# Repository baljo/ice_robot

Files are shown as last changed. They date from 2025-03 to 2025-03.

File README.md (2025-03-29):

# Ice Curing Rover

## The Problem

Too many persons get injured (or worse) due to icy conditions, in the US alone there are [tens of thousands of injuries](https://www.bls.gov/opub/ted/2016/42480-work-injuries-involved-ice-sleet-or-snow-in-2014.htm) involving ice, sleet, or snow. Typically, the city or state is responsible for ensuring public roads are safe, but responsibility shifts to you at the start of your own driveway. Thus, you need to ensure it is safe yourself. You can, of course, salt or sand your icy driveway manually, just as you can mow your lawn, vacuum your home, or wash dishes by hand. While curing your driveway from ice might be enjoyable for some, it’s tedious for others. If you find yourself in the latter group, read on for a solution!

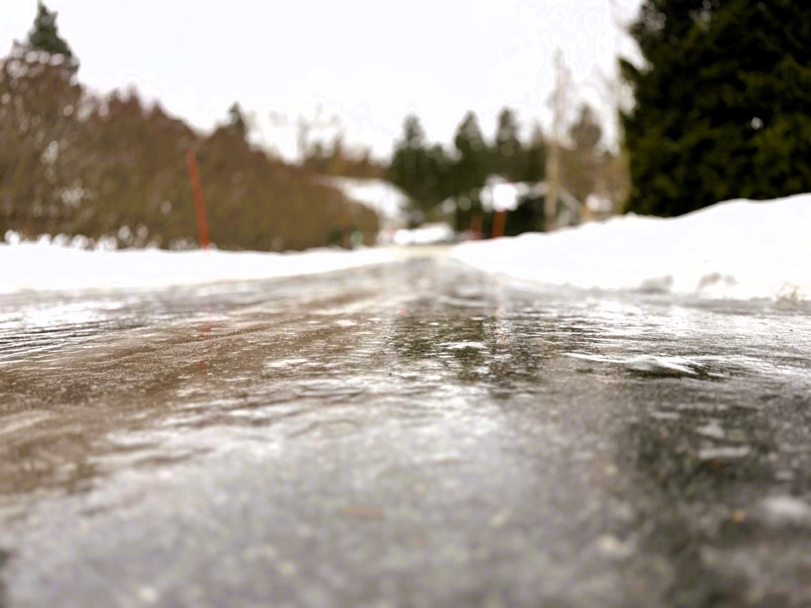
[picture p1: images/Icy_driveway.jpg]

--*Finland, February 22, 2025*--

## The Solution

Meet **Ice Beat-Le**, a symphatethic looking rover designed to combat ice by spreading salt, sand, or other suitable materials on your driveway or path. The rover is driven by six wheels and navigates using IR sensors ("eyes") to lock onto an IR beacon.

For the rover’s MCU, I selected the Particle Photon 2 because it's versatile, powerful, yet easy to work with. The IR beacon currently uses a Propeller Activity Board from Parallax because it includes an onboard D/A chip. If another Photon 2 had been available, I would likely have redesigned the beacon circuit and software to use Pulse Width Modulation (PWM) instead of the D/A chip.

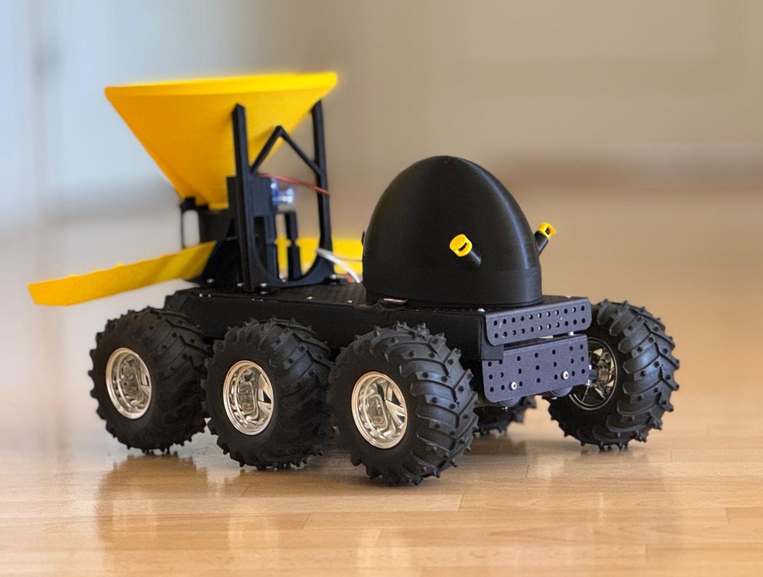
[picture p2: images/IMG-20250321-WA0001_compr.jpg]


### How does it work?

Although the rover looks complex due to its electronic components, motors, servo, and mechanical parts, it is actually quite straightforward, even minimalistic. There are no unnecessary bells and whistles - the rover does exactly what it’s intended to do, nothing more, nothing less. However, the journey of designing and building the rover involved overcoming numerous technical challenges.

#### Navigation

Navigation is achieved using an IR beacon transmitting a 38 kHz IR signal of varying intensity, utilizing the Sony protocol—the same used by many TV remote controls. Unfortunately, the IR receivers ("eyes") on the rover can only detect whether a modulated IR signal is present, not its intensity. This limitation makes it impossible to navigate using a constant IR signal alone, as the rover wouldn’t be able to determine if it's to the left or right of the beacon’s beam.

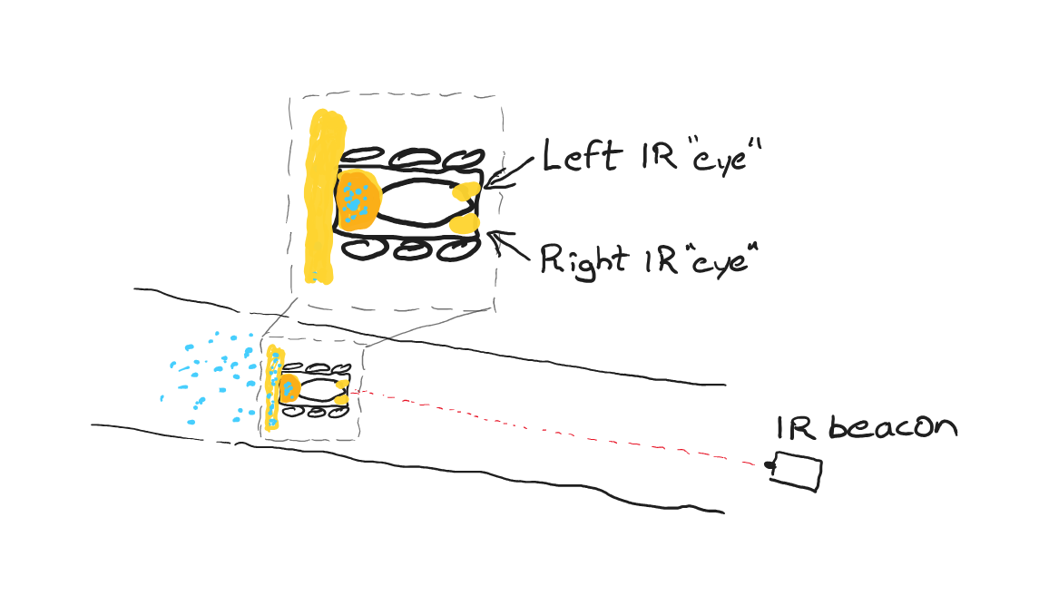
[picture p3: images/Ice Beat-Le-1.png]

--*Rover on a driveway*--

To overcome this issue, I adopted a [solution](https://learn.parallax.com/courses/ir-beacon-seeking-activitybot-with-blocklyprop/) that involves varying the intensity of the IR signal. By modulating both the brightness and pulsing of the beacon, the rover measures how frequently it detects the IR signal, allowing it to determine its orientation relative to the beacon.

To generate both the modulated (pulsed) IR signal AND the varying brightness, two different signals are fed into the LED at the same time. The positive leg of the LED connects to an I/O pin, where the code is sending it pulses by turning it on and off 38000 times per second. The negative leg of the LED connects to a D/A-pin, which is changing its voltage output from 0V (full brightness for the LED) to 1.6V (nearly off). Why is 0V bright and 1.6V dim? Because this is where the negative leg is connected. The result is that the “Sawtooth”-like output of D/A is subtracted from the 3.3V pulses from the I/O pin:

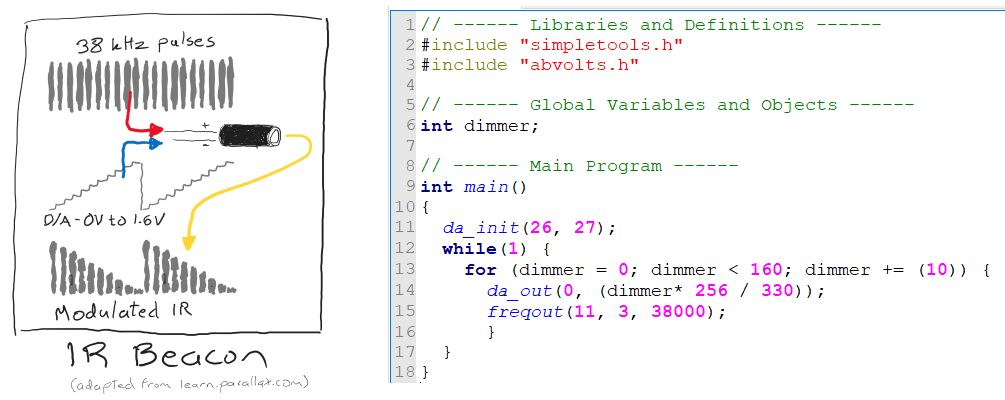
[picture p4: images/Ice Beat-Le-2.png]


The rover counts how often each IR sensor detects the beacon's light. If one side detects fewer pulses than the other (indicating that side is farther from the beacon), the rover turns in the opposite direction. E.g., in the driveway sketch further above, the left sensor receives less light than the right, and thus the rover turns right. Since IR signals can be slightly erratic due to external interference, each receiver uses a moving average to stabilize readings.

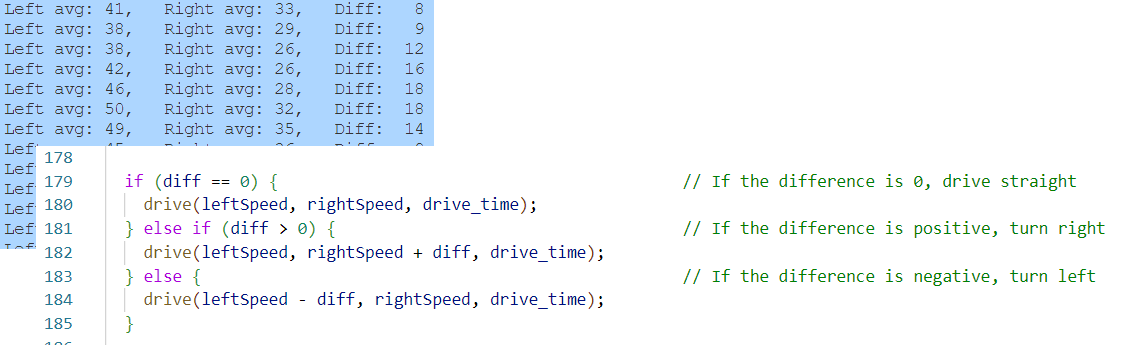
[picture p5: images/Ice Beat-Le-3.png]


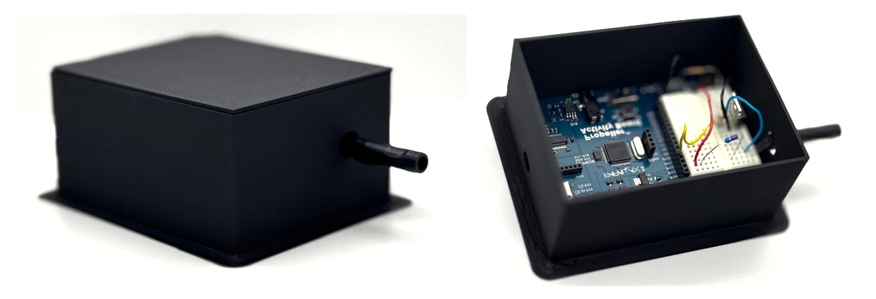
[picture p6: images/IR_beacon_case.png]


#### Sanding/Salting 

In the name of simplicity, and instead of inventing a salting mechanism needing a strong motor, I decided to use a force available to all of us for free → gravity. Sand, salt, or any other suitable material is poured into the container which has a hole in the bottom. To avoid that the sand falls away directly, a servo-controlled lid is opened or closed within the main control program. The sand falls down on the spreader which spreads it over approximately half a meter in width as the rover moves forward. If large particles are used, there's a risk of them clogging the container opening. However, as the rover doesn't have differential steering, it twitches a bit when alternating between driving, turning, and coasting, and I found out that this leads to that potential clogs are easily dissolved.

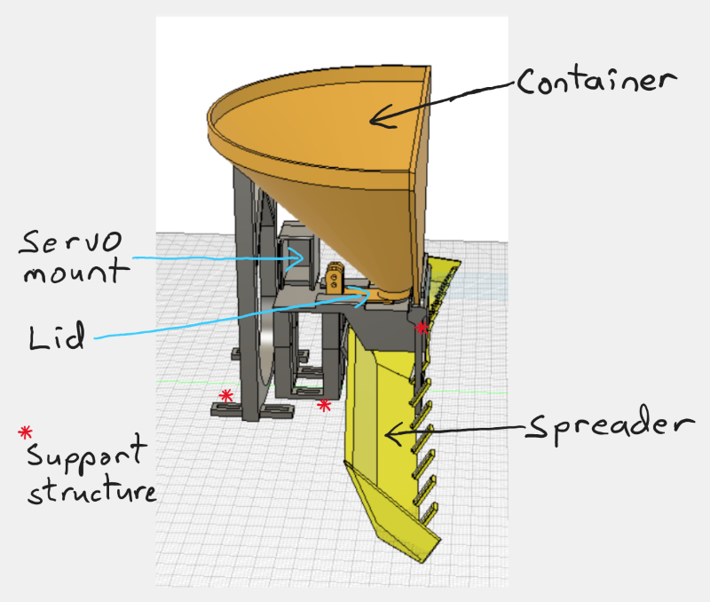
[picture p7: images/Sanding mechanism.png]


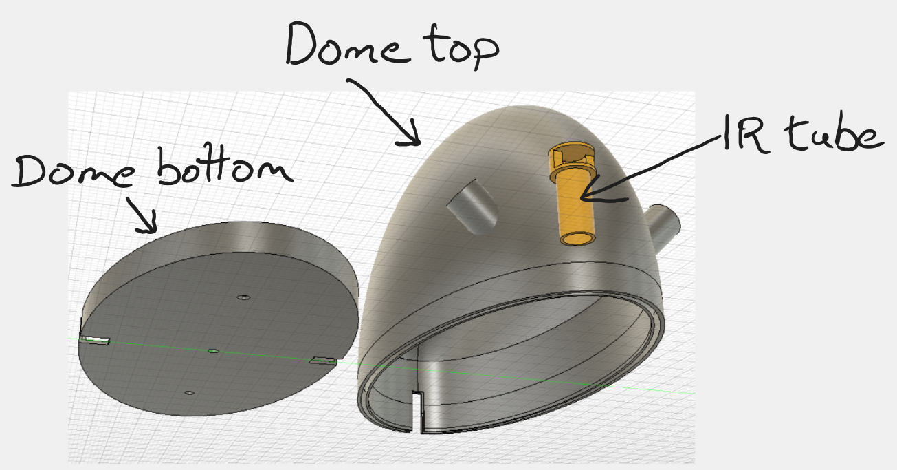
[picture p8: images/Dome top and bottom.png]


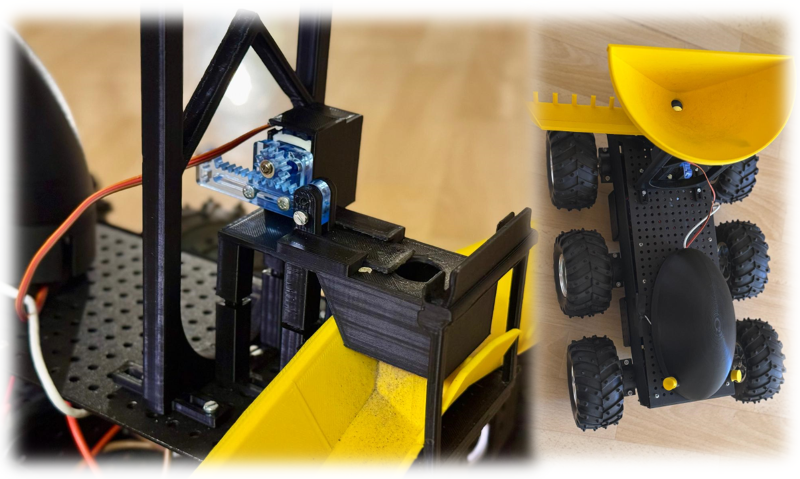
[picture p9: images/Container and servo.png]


## Materials Required

**Rover**
- [Particle Photon 2](https://store.particle.io/products/photon-2?srsltid=AfmBOopQNaLMpaWTah99rLqtw8SrwQJ14wpPAscubC-w2jhXiWBzn8VZ)
- Dagu Wild Thumper 6WD (my rover included 6 motors and 2 HB-25 motor controllers)
- 38 kHz Infrared IR Receiver, e.g. [this](https://www.jameco.com/z/TSOP34138-Vishay-Infrared-IR-Receiver-38Khz-Carrier-Frequency-Use-with-Parallax-350-00017-Boe-Sumo_2109691.html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) 
- [Kitronik Linear Actuator Kit](https://kitronik.co.uk/products/2595-linear-actuator?_pos=3&_sid=e648f346a&_ss=r)
- 5V power for the Photon 2, e.g. a small powerbank
- separate power supply recommended for the motors, max 7.5 VDC; remember to connect grounds
- large breadboard
- 2 servo headers (for HB-25 motor controllers)
- Two 10kΩ resistors
- assorted wires

**IR Beacon**
- [Propeller Activity Board](https://www.parallax.com/product/propeller-activity-board-wx/), or any other microcontroller board with an D/A-chip. It is also possible to use PWM (Pulse Width Modulation) to replicate change in intensity.
- [TSAL6200 IR LED](https://www.partco.fi/en/leds/special-purpose-leds/17474-tsal6200.html), TSAL6100 even better as it has narrower angle
- [IRLZ44N Mosfet](https://www.partco.fi/en/electronic-components/actives/bjt-and-fet/switching-fets-n-channel/5057-irlz44n.html)
- 2.2Ω Resistor
- 10kΩ Resistor
- 5V power for the microcontroller, e.g. a powerbank
- assorted wires

**Note:** Ensure the program cycles the IR LED; constant operation may burn out the LED or resistor. A MOSFET is required to handle higher current beyond the MCU’s capability.

## Assembly Instructions

- Assemble the rover itself according to instructions, my rover came preassembled as it was a used one.

- 3D-print the different components, most of them do not need supports if they are rotated properly. For most parts I used an infill of 10-20 %. 
- Feel free to redesign the components according to your platform and needs. Remember to add tolerances when designing pieces that need to fit together!

### Wiring and Schematics

#### Rover Electronics

- Photon 2 connections

| Photon 2 | To | 
|--- |---|
| D15 | Left motor signal  |  
| D1 | Right motor signal |  
| D2 | Left IR signal |  
| D10 | Right IR signal | 
| D16 | Lid servo signal |  
| VUSB | Lid servo power | 

- Fritzing diagram 

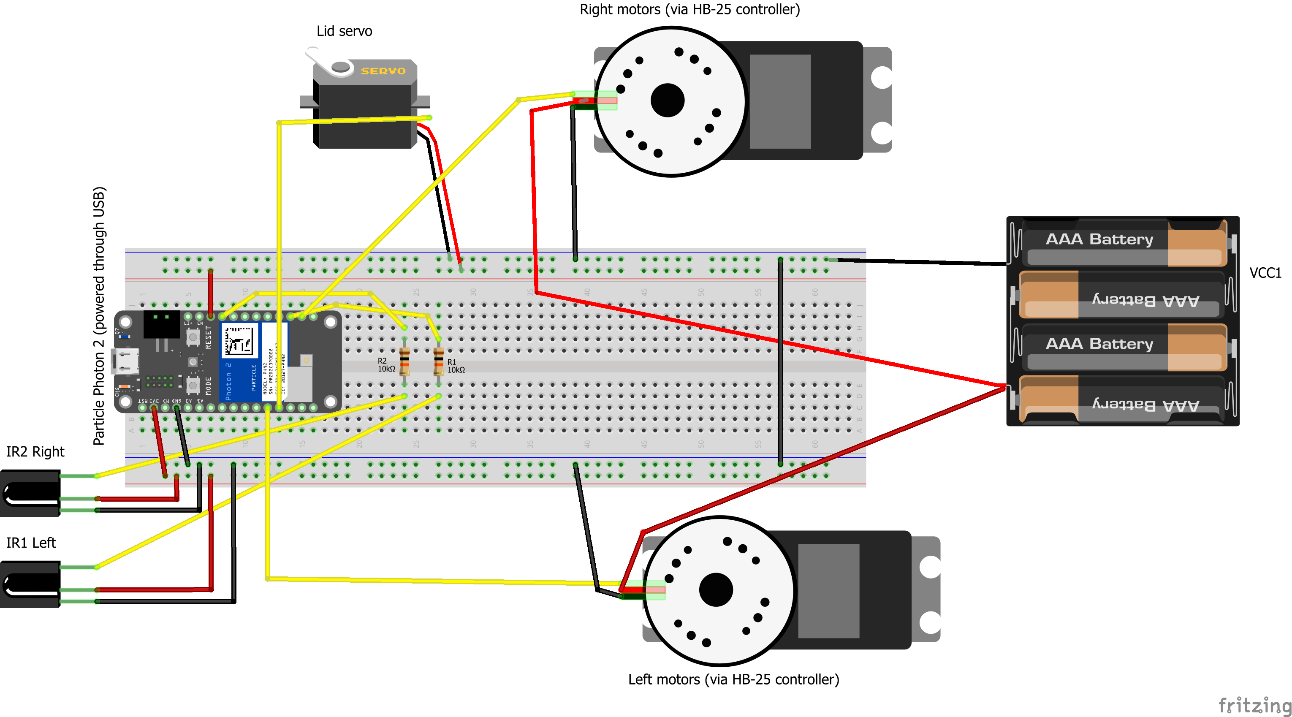
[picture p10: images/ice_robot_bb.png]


- Close-up photo, do note that the lid controlling servo is left out of the photo for clarity, it is connected to VUSB and D16.

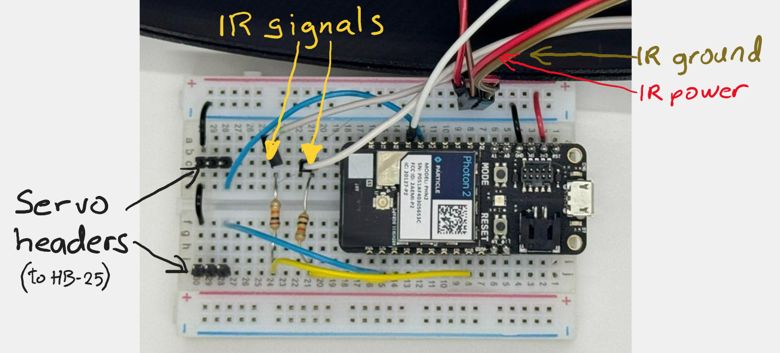
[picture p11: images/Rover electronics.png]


#### IR Beacon

- Fritzing diagram. In my setup I'm using the Propeller Activity Board as it has a D/A-chip.

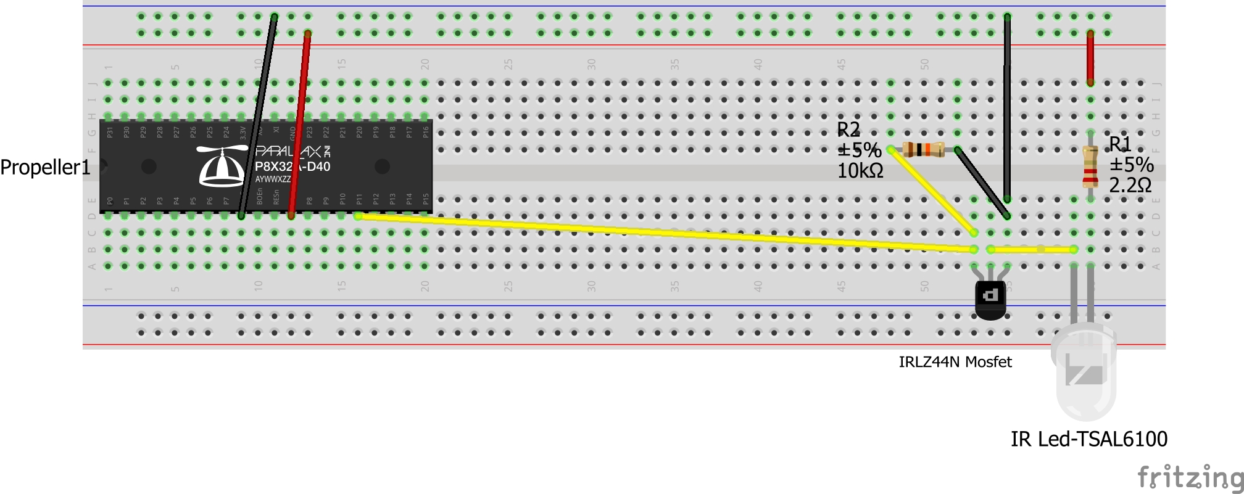
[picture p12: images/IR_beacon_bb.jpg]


- Close-up photo. To narrow the infrared beam a bit, the IR LED is equipped with a plastic straw enclosed in black electronic tape.

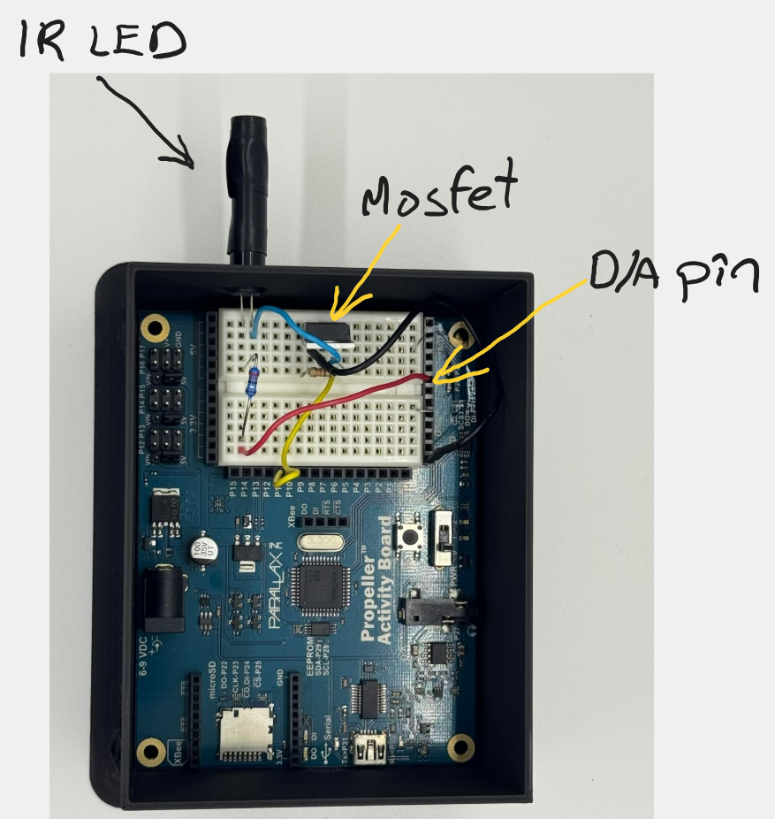
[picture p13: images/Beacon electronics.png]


## Software Description

Below a description of the main functions.

### IR Beacon

The beacon program is very simple, it pulses out IR light with a frequency of 38 kHz, in this case using pin 11 on the Propeller MCU. Every pulse is 3 milliseconds in length. The intensity is changed between nearly off until fully lit (330 = 3.3V).

```
// ------ Libraries and Definitions ------
#include "simpletools.h"
#include "abvolts.h"

// ------ Global Variables and Objects ------
int dimmer;

// ------ Main Program ------
int main() {
  da_init(26, 27);
  while(1) {
    for (dimmer = 0; dimmer < 160; dimmer += (10)) {
      da_out(0, (dimmer* 256 / 330));
      freqout(11, 3, 38000);
    }
  }
}

```

### Photon 2

- The function `IR_read` reads the IR sensors 96 times per loop and accumulates the pulses read per sensor. The higher the number is, the closer or more aligned the sensor is to the beacon.

```
// Read the IR sensors
// leftOut and rightOut are passed by reference
// They will be updated with the number of times the IR sensor was triggered
// The higher the number, the closer the sensor is to an object

void IR_read(int &leftOut, int &rightOut) {
  int leftIR = 0;
  int rightIR = 0;
  
  // Sample 96 times (16 * 6)
  for(int n = 0; n < 96; n++) {
    leftIR  += !digitalRead(LEFT_IR_PIN);                   // Read the digital value of the IR sensor
    rightIR += !digitalRead(RIGHT_IR_PIN);                  // Read the digital value of the IR sensor
    delay(1);                                               // 1 ms between samples
  }
  
  // Assign results to the provided references
  leftOut  = leftIR;
  rightOut = rightIR;
}
```

- The function `drive` drives the rover by the speed received for each side. The motors are off when the value is 90, and as they need to rotate in opposite directions the given speed is added to 90 for the left motors, and subtracted from 90 for the right motors. 

```
void drive(int left_speed, int right_speed, int time) {
  left.write(90 + left_speed);    // Move left motor forward
  right.write(90 - right_speed);  // Move right motor forward
  delay(time);                    // Delay selected time
}
```

- The main loop consists of reading the IR sensors, calculate a rolling average for each of them, and based on possible difference between the readings turn right or left. As the rover's minimum speed is too fast indoors, it is alternating between driving forware, coasting, or turning.

```
  IR_read(leftIR, rightIR);                                 // Read the IR sensors  
----------------------
  int left_avg = calculateRollingAverage(leftIR, 0);        // Rolling average for Sensor 1
  int right_avg = calculateRollingAverage(rightIR, 1);      // Rolling average for Sensor 2
  int diff = coeff * (left_avg - right_avg);                // Calculate the difference between the IR sensors
----------------------
  int left_avg = calculateRollingAverage(leftIR, 0);        // Rolling average for Sensor 1
  int right_avg = calculateRollingAverage(rightIR, 1);      // Rolling average for Sensor 2
  int diff = coeff * (left_avg - right_avg);                // Calculate the difference between the IR sensors
----------------------
// If either leftIR or rightIR is very low, don't move
  while (left_avg <= 2 || right_avg <= 2 && left_avg != right_avg) {
    Log.info("Seeking IR signal");

    IR_read(leftIR, rightIR);
    left_avg = calculateRollingAverage(leftIR, 0);          // Rolling average for Sensor 1
    right_avg = calculateRollingAverage(rightIR, 1);        // Rolling average for Sensor 2
    diff = coeff * (left_avg - right_avg);                  // Calculate the difference between the IR sensors

    Log.info("   Left avg: %2d,   Right avg: %2d,   Diff: %3d", left_avg, right_avg, left_avg - right_avg);
  }

  if (diff == 0) {                                          // If the difference is 0, drive straight
    drive(leftSpeed, rightSpeed, drive_time);
  } else if (diff > 0) {                                    // If the difference is positive, turn right
    drive(leftSpeed, rightSpeed + diff, drive_time);
  } else {                                                  // If the difference is negative, turn left
    drive(leftSpeed - diff, rightSpeed, drive_time);
  }

  drive(leftSpeed / 3, rightSpeed / 3, drive_time);         // Drive forward at a slower speed, otherwise the robot will drive too fast
```

## Final Demonstration

A YouTube video is found [here](https://youtu.be/t5bE52Lg39M).



## Conclusion & Next Steps

### Issues overcome

As mentioned earlier, while the final result appears minimalistic, the journey to achieve it was neither simple nor straightforward. Indeed, there were several challenges and setbacks along the way. Finding a reliable solution for outdoor navigation took considerable experimentation - I had to acquire and test various IR LEDs and receivers extensively before finding an effective combination. Additionally, learning Fusion 360 from scratch, designing twelve distinct 3D-printed components, and printing numerous iterations consumed significant time and roughly one kilogram of filament, of which approximately 80% ended up as scrap.

### Future enhancements

This initial version of the rover isn't yet fully autonomous; for safety, it currently only moves when the IR beacon is transmitting. Presently, it moves forward and turns left or right as needed, but it would be relatively straightforward to add functionality enabling it to reverse its route or cover wider areas. Expanding the coverage could be achieved either by implementing a larger spreader mechanism or programming the rover to follow multiple parallel lanes.

To achieve full autonomy, adding bumper switches or distance sensors would allow obstacle avoidance, while integrating an odometer or a high-precision (centimeter-level) differential GPS would significantly enhance navigation capabilities—though these would add to the cost.

For permanent installations, the existing breadboard setup should be replaced by a custom PCB or at least a soldered protoboard. Additionally, the two separate battery systems currently in use could be consolidated into a single, higher-capacity battery for improved efficiency and runtime.

### Final Conclusions

This Ice Curing Rover, affectionately called Ice Beat-Le, is a six-wheeled autonomous vehicle that spreads sand or salt on icy driveways, helping reduce winter slip hazards. At the heart of the rover is the Particle Photon 2, whose powerful yet beginner-friendly platform made it easy to prototype, program, and control the robot’s complex behaviors with minimal overhead. Navigating via a modulated IR-beacon and using a gravity-fed dispenser controlled by a servo, the rover is a compact and cost-effective solution built with 3D-printed parts and off-the-shelf components. The Photon 2’s combination of real-time control, built-in connectivity, and versatility made it the ideal choice for this project - especially for balancing simplicity with performance. With a few additions, such as obstacle sensors or lane logic, the rover could easily evolve into a fully autonomous ice-clearing assistant.

While the *road* was bumpy to some *degree*, it *led* eventually to the goal, and it is now *ice* free! 

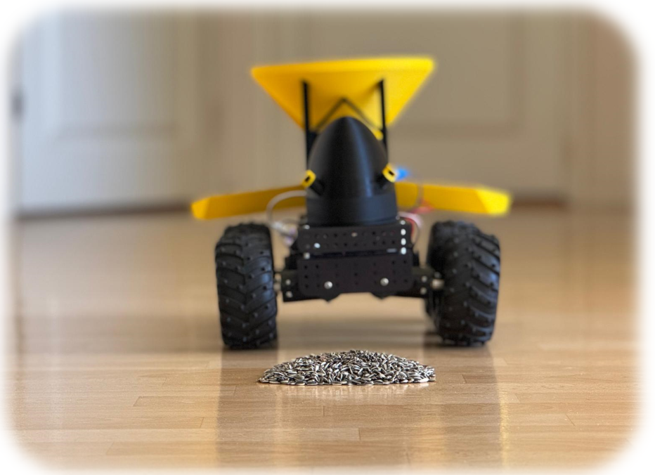
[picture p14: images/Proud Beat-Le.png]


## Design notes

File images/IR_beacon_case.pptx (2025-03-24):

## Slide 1

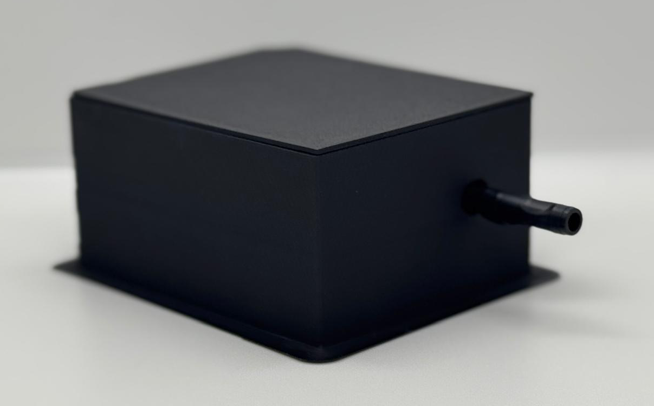
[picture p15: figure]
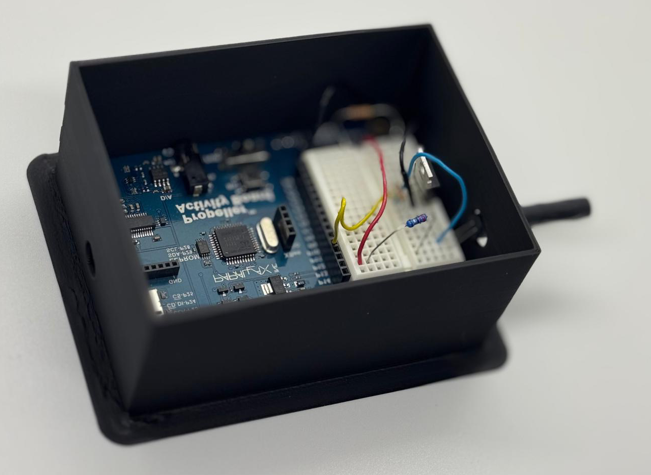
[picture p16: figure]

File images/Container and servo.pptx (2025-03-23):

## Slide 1

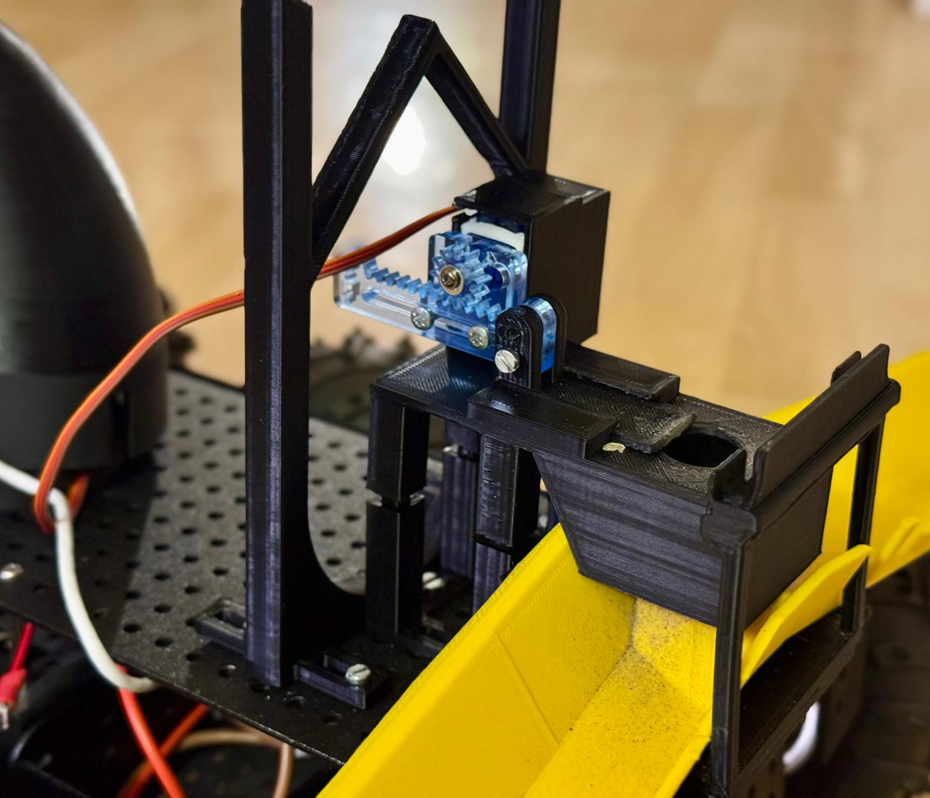
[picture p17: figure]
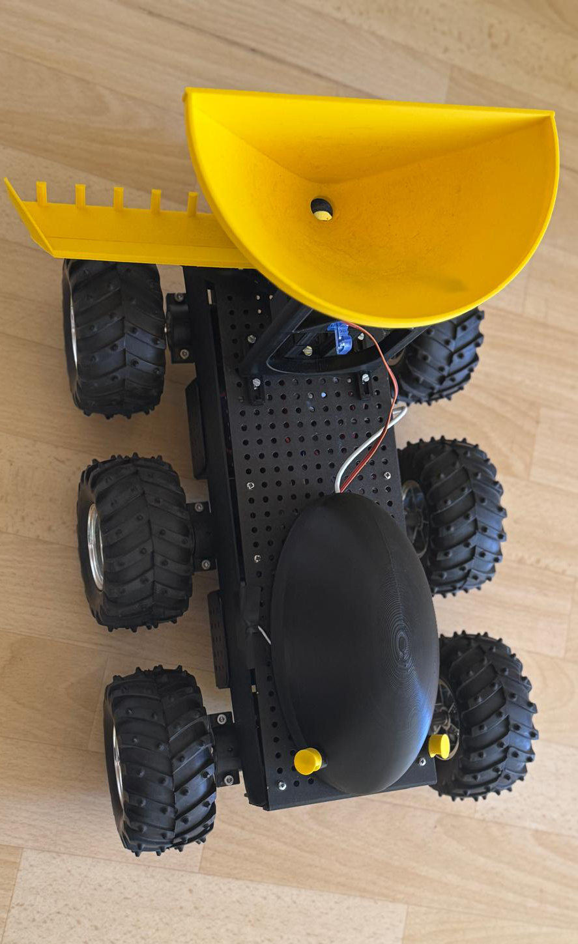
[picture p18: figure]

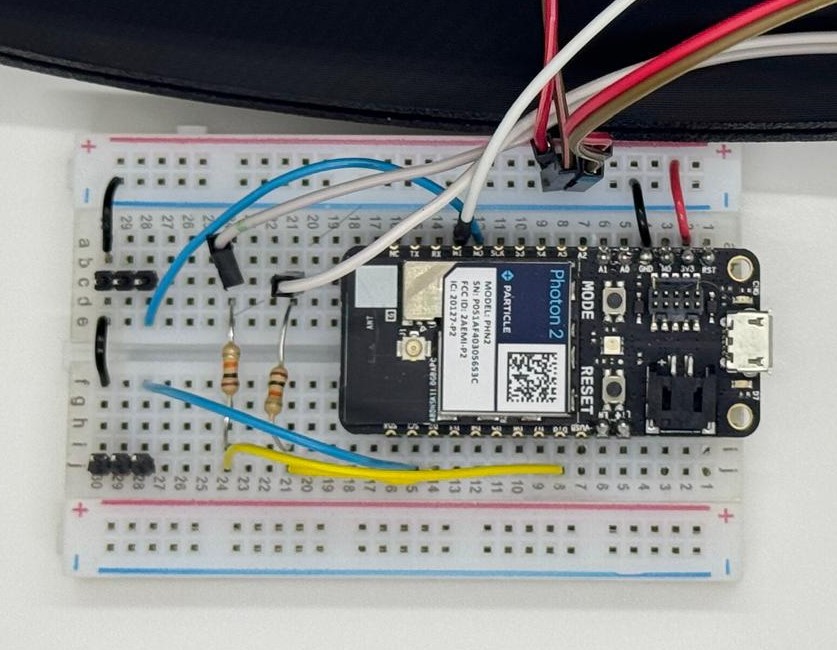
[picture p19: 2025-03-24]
images/Rover_electronics.jpg

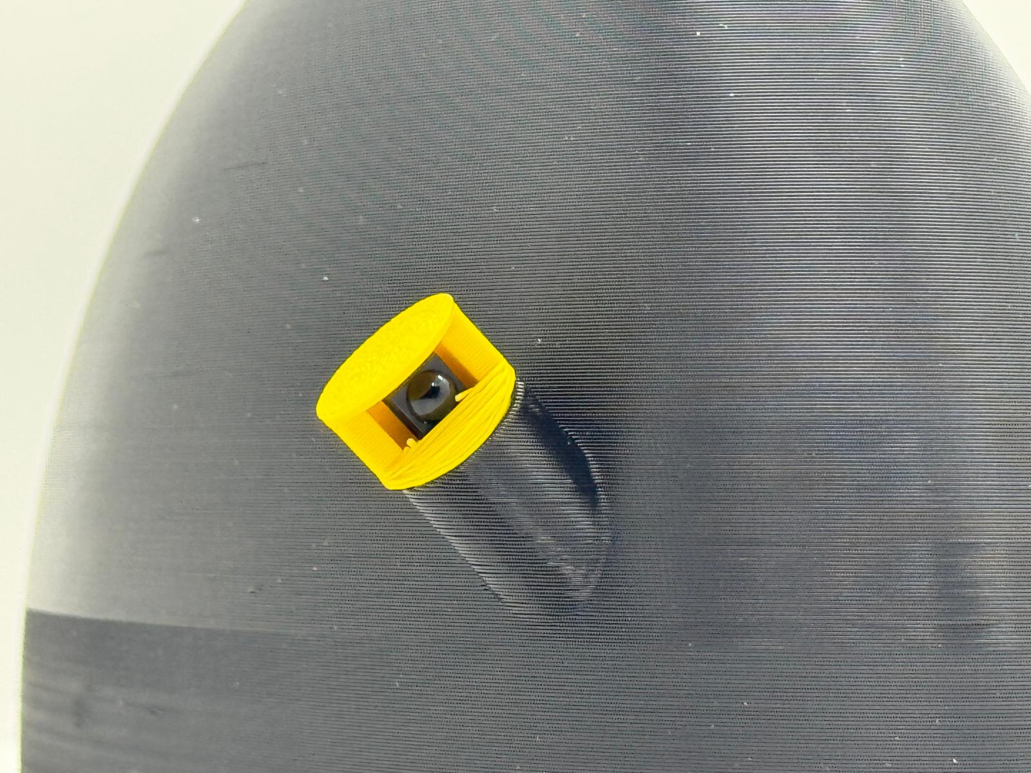
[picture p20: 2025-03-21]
images/IMG-20250321-WA0013.jpg

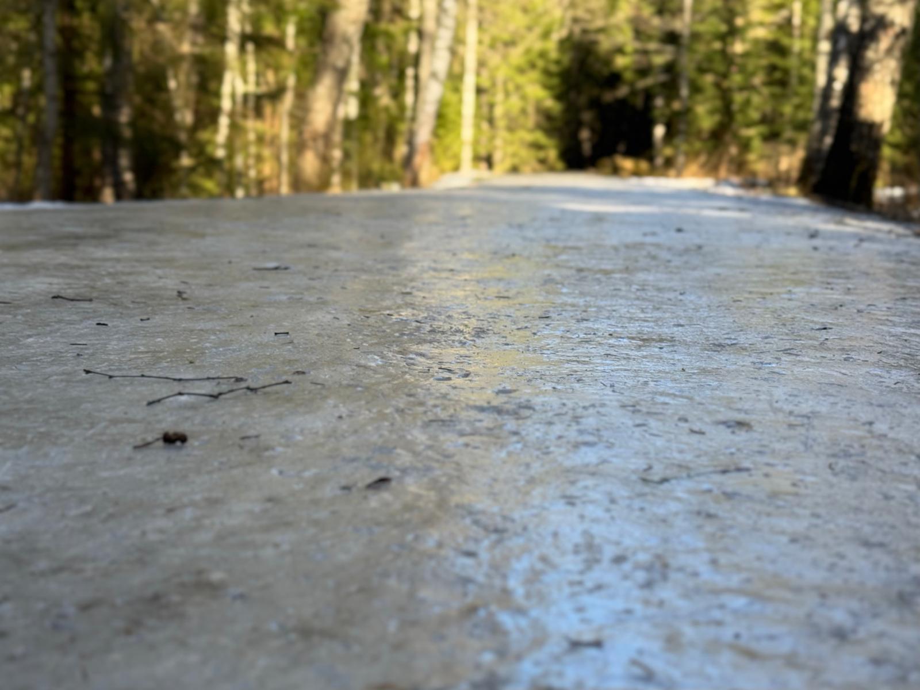
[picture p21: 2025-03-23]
images/Icy_driveway_2.jpg

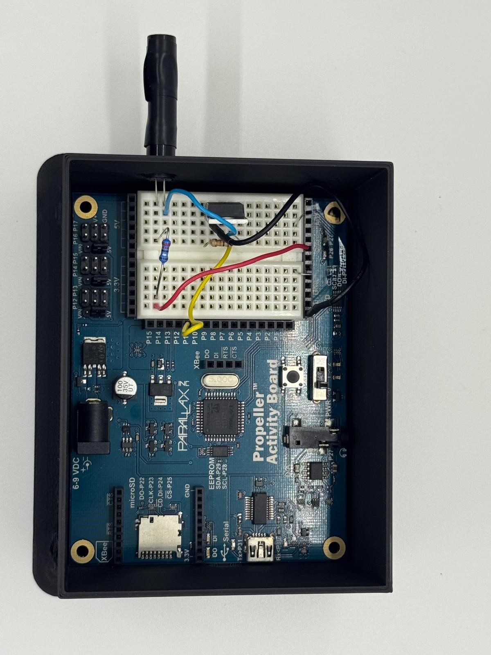
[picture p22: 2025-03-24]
images/IMG-20250321-WA0008.jpg

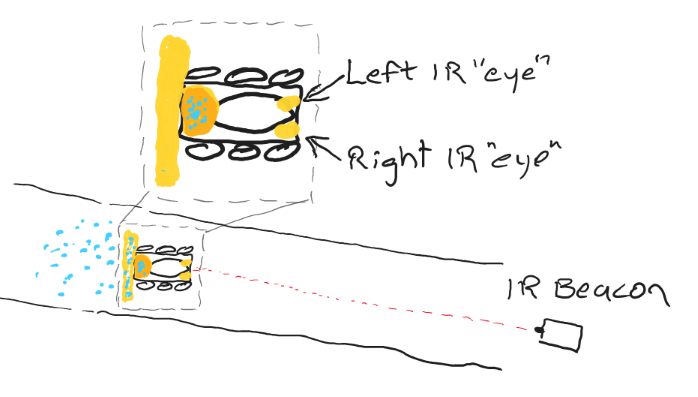
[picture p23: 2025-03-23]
images/Ice Beat-Le-01.png

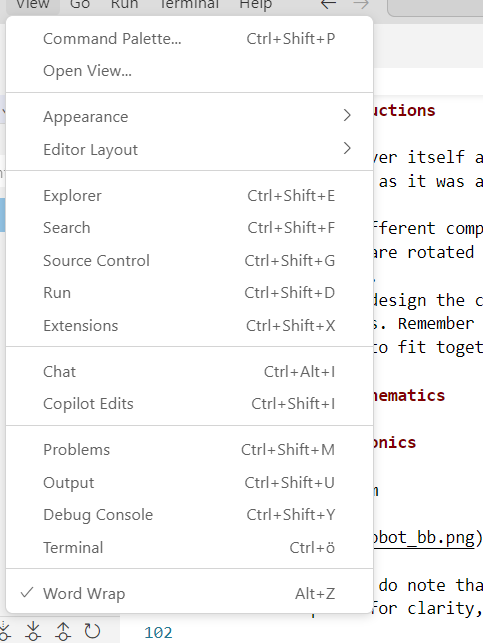
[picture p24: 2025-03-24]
image.png

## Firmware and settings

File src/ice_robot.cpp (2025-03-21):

/* 
 * Project Ice Beat-Le
 * Author: Thomas Vikström
 * Date: 21.3.2025
 * Description: This program is designed to control a robot with two motors and two IR sensors.
 * 
 */

// Include Particle Device OS APIs
#include "Particle.h"
#include <cstdlib> // Include the necessary library for random function


// Let Device OS manage the connection to the Particle Cloud
SYSTEM_MODE(AUTOMATIC);

// Run the application and system concurrently in separate threads
SYSTEM_THREAD(ENABLED);

// Show system, cloud connectivity, and application logs over USB
// View logs with CLI using 'particle serial monitor --follow'
SerialLogHandler logHandler(LOG_LEVEL_INFO);

Servo left;                                       // create servo object to control a servo
Servo right;                                      // create servo object to control a servo
Servo lid;                                        // create servo object to control a servo

const int LEFT_MOTOR_PIN = D15; 
const int RIGHT_MOTOR_PIN = D1;
const int LEFT_IR_PIN = D2;
const int RIGHT_IR_PIN = D10;
const int LID_PIN = D16;


// ------ Functions ------

void forward(int speed, int time) {
  left.write(90 + speed);   // Move left motor forward
  right.write(90 - speed);  // Move right motor forward
  delay(time);              // Delay selected time
}

void drive(int left_speed, int right_speed, int time) {
  left.write(90 + left_speed);    // Move left motor forward
  right.write(90 - right_speed);  // Move right motor forward
  delay(time);                    // Delay selected time
}

void stop(int time) {
  left.write(90);         // Stop both motors
  right.write(90);   
  delay(time);            // Delay selected time 
}


// Function to calculate the rolling average for a given sensor
float calculateRollingAverage(float newSample, int sensorID) {
  static int amount = 3;
  static float samples[2][3] = {{0}}; // Arrays to store the last 10 samples for two sensors
  static int index[2] = {0};          // Current index for each sensor
  static int count[2] = {0};          // Number of samples added (up to 10) for each sensor
  static float sum[2] = {0};          // Sum of the samples for each sensor

  // Subtract the oldest sample from the sum (if array is full)
  sum[sensorID] -= samples[sensorID][index[sensorID]];

  // Add the new sample to the array and update the sum
  samples[sensorID][index[sensorID]] = newSample;
  sum[sensorID] += newSample;

  // Update the index for the sensor
  index[sensorID] = (index[sensorID] + 1) % amount;

  // Increment count up to 10 for the sensor
  if (count[sensorID] < amount) {
      count[sensorID]++;
  }

  // Return the rolling average for the sensor
  return sum[sensorID] / count[sensorID];
}


// Read the IR sensors
// leftOut and rightOut are passed by reference
// They will be updated with the number of times the IR sensor was triggered
// The higher the number, the closer the sensor is to an object

void IR_read(int &leftOut, int &rightOut) {
  int leftIR = 0;
  int rightIR = 0;
  
  // Sample 96 times (16 * 6)
  for(int n = 0; n < 96; n++) {
    leftIR  += !digitalRead(LEFT_IR_PIN);                   // Read the digital value of the IR sensor
    rightIR += !digitalRead(RIGHT_IR_PIN);                  // Read the digital value of the IR sensor
    delay(1);                                               // 1 ms between samples
  }
  
  // Assign results to the provided references
  leftOut  = leftIR;
  rightOut = rightIR;
}


// --------------------------------------------------------------------------
// Open and close the lid
// --------------------------------------------------------------------------
void move_lid() {      

  int speed = 5;
  int wait = 15;
  int servo_pos = 0;              // variable to store the servo position


  for (servo_pos = 170; servo_pos >= 1; servo_pos -= speed) {
      lid.write(servo_pos);
      delay(wait);
  }

  delay(wait);

  for (servo_pos = 0; servo_pos < 170; servo_pos += speed) {   
    lid.write(servo_pos);
    delay(wait);
  }

}



void setup() {


  // Set up the IR sensors
  pinMode(LEFT_IR_PIN, INPUT);                               // sets the digital pin as input
  pinMode(RIGHT_IR_PIN, INPUT);                              // sets the digital pin as input

  // Set up the motors
  left.attach(LEFT_MOTOR_PIN);                               // attaches the left servo  to the servo object
  right.attach(RIGHT_MOTOR_PIN);                             // attaches the right servo to the servo object
  lid.attach(LID_PIN);                                       // attaches the lid servo to the servo object
}


void loop() {
  int leftIR = 0;
  int rightIR = 0;
  
  IR_read(leftIR, rightIR);                                 // Read the IR sensors  

  int leftSpeed = 23;                                       // Set the speed for the left motor (the left motor is slower)
  int rightSpeed = 20;                                      // Set the speed for the right motor
  int drive_time = 100;                                     // Set the drive time        
  int coeff = 3;                                            // Set the coefficient for the difference between the IR sensors  

  int left_avg = calculateRollingAverage(leftIR, 0);        // Rolling average for Sensor 1
  int right_avg = calculateRollingAverage(rightIR, 1);      // Rolling average for Sensor 2
  int diff = coeff * (left_avg - right_avg);                // Calculate the difference between the IR sensors

  Log.info("   Left avg: %2d,   Right avg: %2d,   Diff: %3d", left_avg, right_avg, left_avg - right_avg);
  

  move_lid();                                                // Open and close the lid

  // If either leftIR or rightIR is very low, don't move
  while (left_avg <= 2 || right_avg <= 2 && left_avg != right_avg) {
    Log.info("Seeking IR signal");

    IR_read(leftIR, rightIR);
    left_avg = calculateRollingAverage(leftIR, 0);          // Rolling average for Sensor 1
    right_avg = calculateRollingAverage(rightIR, 1);        // Rolling average for Sensor 2
    diff = coeff * (left_avg - right_avg);                  // Calculate the difference between the IR sensors

    Log.info("   Left avg: %2d,   Right avg: %2d,   Diff: %3d", left_avg, right_avg, left_avg - right_avg);
  }


  if (diff == 0) {                                          // If the difference is 0, drive straight
    drive(leftSpeed, rightSpeed, drive_time);
  } else if (diff > 0) {                                    // If the difference is positive, turn right
    drive(leftSpeed, rightSpeed + diff, drive_time);
  } else {                                                  // If the difference is negative, turn left
    drive(leftSpeed - diff, rightSpeed, drive_time);
  }

  drive(leftSpeed / 3, rightSpeed / 3, drive_time);         // Drive forward at a slower speed, otherwise the robot will drive too fast
}
